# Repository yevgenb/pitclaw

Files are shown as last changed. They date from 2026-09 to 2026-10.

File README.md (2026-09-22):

# Pit Claw logo Pit Claw



BBQ temperature monitor and controller built around the WT32-SC01 Plus: an
ESP32-S3 with a 3.5-inch, 480×320 landscape capacitive touchscreen. Pit Claw reads
one pit probe and two meat probes, controls a blower and optional servo damper,
and provides a web dashboard for monitoring and control. The touchscreen and
temperature control work without Wi-Fi.

## Current project state

As of **9 September 2026**:

| Area | State |
| --- | --- |
| Firmware | Version **0.2.0**, built and flashed to a WT32-SC01 Plus; upload verified and the device responded after reboot. |
| Touchscreen | LVGL Home, Graph, Settings, temperature editors, shared alarms, and first-boot setup are implemented. The latest polish is included in the flashed build. |
| Web interface | Live temperatures, history and prediction graphs, session controls/export, settings, and manual firmware OTA. Supports deployment under an Nginx path prefix. |
| Carrier PCB | **Rev B-T2F0-A5807-S4** routed prototype. Recorded KiCad ERC, DRC, schematic parity, and unconnected-item checks pass. A reviewed bare-board fabrication package is available; physical qualification remains. |
| Enclosure | **r7 landscape fit prototype**, with exported STLs, fit coupons, and a print guide. Physical module and printed-part fit still need verification. |

The firmware and simulator builds, **132 native test cases**, and the headless
LVGL checks passed on 8 September 2026. The LVGL checks include 123 navigation
taps and editor, unit, alarm, probe-state, and layout transitions. This validation
does not establish smoker temperature accuracy or qualify the new carrier's
electrical loads, thermal behavior, or physical fit.

## Touchscreen

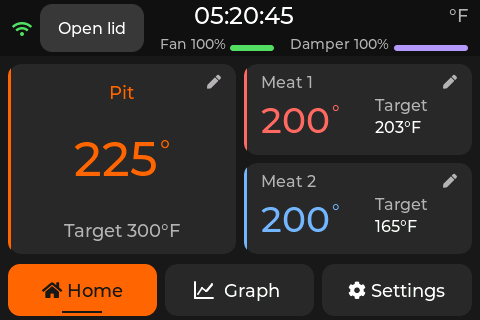
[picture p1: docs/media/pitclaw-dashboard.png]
Current Pit Claw touchscreen dashboard


The current dashboard uses large temperature readings, rounded cards and
navigation buttons, neutral status labels, and consistent edit icons. Smaller
degree symbols follow changing values and disappear for disconnected probes.
The image above is a native 480×320 LVGL render with example readings.

- Tap the pit card to change its setpoint, or a meat card to edit that probe's
  target. Tap for one-degree steps or hold for five-degree steps; Cancel discards
  the draft value.
- Switch between Fahrenheit and Celsius without changing the stored control
  targets. Graph history uses elapsed sample time and a dashed setpoint line.
- Alarm controls remain available on Home, Graph, Settings, and above an open
  editor. Disconnected probes display dashes.
- Setup provides Back navigation, Wi-Fi connection feedback, live probe checks,
  and separate fan, servo, and buzzer test buttons.

## Control and monitoring

- **Three probe inputs:** one pit and two meat channels, using calibrated
  thermistor probes with 2.5 mm jacks. Thermoworks Pro-Series is the intended
  probe family; other probes require suitable coefficients and calibration.
- **PID control:** fan-only, fan-and-damper, and damper-priority modes, with
  startup handling, lid-open detection, and output shutdown on a pit-probe fault.
- **Alarms:** local buzzer, browser audio, and configurable Pushover notifications.
- **Cook sessions:** temperature history, predicted meat completion times, and
  CSV/JSON export. Download a session before starting a new one.
- **Configuration:** persistent settings, probe calibration, and Wi-Fi reconnect.

## Web interface

Pit Claw web dashboard

Open `http://bbq.local` or the controller's LAN IP from a device on the same
network. The dashboard uses WebSocket updates and also works behind an Nginx
directory prefix such as `/newbbq/`; see the
[reverse-proxy guide](firmware/docs/reverse-proxy.md).

PWA installation, service-worker caching, and browser notifications need a secure
context; use HTTPS on the reverse proxy for those features. Live readings still
require a connection to the controller.

Manual firmware updates are available at `/update`. Automatic GitHub release
checks are disabled in the current PlatformIO configuration. `firmware.bin`
includes the web UI, so one firmware upload updates both interfaces while
preserving LittleFS settings and session history.

## Hardware and enclosure

The active design is the
[Rev B-T2F0-A5807-S4 carrier](hardware/carrier-revb/README.md), a 60×92 mm board
with PCB-mounted probe jacks, a blower/servo connector, a 12 V barrel inlet,
an Adafruit 5807 USB-C PD module, and a Traco TSR 2-2450N 5 V / 2 A converter.
A relay selects wall power when present and USB-PD otherwise.

| Resource | Contents |
| --- | --- |
| [Carrier design](hardware/carrier-revb/README.md) | Circuit, power limits, module mounting, and remaining qualification work |
| [Wiring guide](docs/wiring.md) | Current connector pin assignments and assembly wiring |
| [Carrier BOM](hardware/carrier-revb/bom/README.md) | Current parts and recorded pricing |
| [Verification](hardware/carrier-revb/verification/README.md) | Native electrical/layout checks and physical validation limits |
| [JLCPCB prototype package](hardware/carrier-revb/fabrication/jlcpcb-2026-09-06/README.md) | Reviewed Gerber/drill archive for a small bare-board order |
| [Fusion enclosure model](enclosure/fusion-r13/pitclaw-enclosure-r13.f3d) | Editable 104×86×44.9 mm controller case |
| [STL package and print guide](enclosure/fusion-r13/README.md) | Top, bottom, probe fascia, display retainer, USB base, coupons, and assembly guide |

The fabrication documentation records no submitted PCB order. Carrier load,
relay-transfer, thermal, and module-fit checks remain, along with printed
enclosure fit checks. Use the [enclosure guide](enclosure/README.md) for the
current controller case and the separate fan/damper assembly.

## Getting started

### 1. Set up the tools

```sh
git clone https://github.com/yevgenb/pitclaw.git
cd pitclaw
```

Install PlatformIO CLI. Windows users can use the repository's setup script:

```powershell
# Run from an elevated PowerShell in the repository root
powershell -ExecutionPolicy Bypass -File scripts\setup-dev.ps1
```

See [firmware development](docs/firmware-development.md) for prerequisites.
Use the current carrier and wiring guides when assembling hardware.

### 2. Build and flash

Run from `firmware/` with the WT32-SC01 Plus connected over USB:

```sh
cd firmware
pio run -e wt32_sc01_plus
pio run -e wt32_sc01_plus --target upload

```

No filesystem upload is needed for the web UI. A filesystem upload replaces
LittleFS and can erase configuration and session data; normal firmware updates
preserve that filesystem. The display board's programming USB port requires
opening the enclosure; the carrier's external USB-C PD port is for power.

For later manual firmware OTA, open `http://bbq.local/update` and upload
`firmware/.pio/build/wt32_sc01_plus/firmware.bin` from the repository root.

### 3. Complete setup

1. Select °F or °C in the touchscreen wizard.
2. Follow the Wi-Fi QR code and portal instructions, or continue offline with Next.
3. Connect the probes and check their live readings.
4. Tap the fan, servo, and buzzer test buttons and confirm each device operates.
5. Finish setup to enter the dashboard.

Hold a finger on the touchscreen for 10 seconds during the boot splash to request
a factory reset.

## Development and validation

The SDL2 desktop simulator runs the production LVGL screens and serves the web
UI at `http://localhost:3000`. Run these commands from `firmware/`:

```sh
# Native control-logic regression tests
pio test -e native

# Desktop simulator; requires SDL2
pio run -e simulator
.pio/build/simulator/program

# Headless production LVGL interaction checks; run after building the simulator
python3 test/ui/run_checks.py

# Web update and reverse-proxy checks
node test/web/test_release_updates.cjs
node test/web/test_reverse_proxy.cjs
```

On Apple Silicon with Homebrew SDL2, use
`CPATH=/opt/homebrew/include pio run -e simulator` if the headers are not found.
The [display test guide](firmware/test/ui/README.md) explains the capture command
and alternate SDL paths. UI screenshots can be regenerated locally on demand.

| Guide | Topics |
| --- | --- |
| [Firmware development](docs/firmware-development.md) | Build, flash, architecture, and configuration |
| [Display checks](firmware/test/ui/README.md) | Real LVGL pointer events, layout checks, and PNG capture |
| [Web UI development](docs/web-development.md) | Simulator profiles, web assets, and WebSocket protocol |
| [Reverse proxy](firmware/docs/reverse-proxy.md) | Nginx path prefixes, WebSockets, HTTPS, and manual OTA routing |
| [3D printed parts](enclosure/README.md) | Current enclosure, legacy parts, and fan assembly |

## License

TBD

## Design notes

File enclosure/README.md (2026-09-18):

# Pit Claw 3D printed parts

The controller enclosure is [Fusion r13](fusion-r13/README.md): a 104 × 86 ×
44.9 mm case with a top bezel, bottom shell, internal display retainer and
removable probe fascia with fitted captured guides. All sixteen insert pilots
are Ø4.2 mm; the full parts include the accepted guide and seam adjustments.
Four internal M3 inserts provide a 72 × 74 mm mounting pattern with screw access
from underneath.

A fifth printable part, the [Adafruit 5807 base](fusion-r13/usb-base/README.md),
replaces both module spacers and the adhesive rear support. It uses the existing
M2 hardware and keeps the same 3 mm board seating height. The user confirmed
the original R13 case fit; its four enclosure parts are unchanged, so **no case
reprint is needed**. Only the new base needs a physical fit check.

- [Print package and editable Fusion model](fusion-r13/pitclaw-enclosure-r13.zip)
- [Print settings, coupons, hardware and assembly](fusion-r13/README.md)
- [Native Fusion design](fusion-r13/pitclaw-enclosure-r13.f3d)
- [Mounting interface](fusion-r13/mount-interface.json)
- [Independent OpenSCAD reference and checks](fusion-r13/reference/README.md)
- [Matching joint coupons](fusion-r13/README.md#coupons) for checking the same guide,
  seam and insert geometry used by the complete enclosure.

The current package has five complete parts and six coupons. Only the latest
controller enclosure is kept in the working tree; older designs remain in Git
history. CAD checks pass. Printed strength and mounting load capacity remain
unrated.

## Separate blower and damper assembly

The smoker-mounted blower/damper is a separate part, retained alongside the
controller enclosure. Use [bbq-fan-assembly.scad](bbq-fan-assembly.scad),
[blower-housing.stl](stl/blower-housing.stl) and
[uds-pipe-adapter.stl](stl/uds-pipe-adapter.stl).

Open the fan source in OpenSCAD, select the desired `part`, render and export in
millimeters. Print the blower housing open-side-up and the pipe adapter upright.
Check fit with the actual fan, servo and smoker intake. Its geometry is separate
from the r13 controller fit verification.

### Hardware

| Qty | Item | Notes |
|-----|---|---|
| 2 | M3x10mm screws | Mount 5015 blower fan to housing |
| 2 | M2 or M2.5 screws | Mount MG90S servo (servo-specific) |
| 1 | Small screw + nut | Attach damper plate to servo horn |
| 2 | Small hose clamps (25-40mm range) | One for pipe adapter to pipe nipple, one for duct to adapter (if not press-fit) |
| 1 | High-temp gasket tape (or PTFE tape) | Wrap around NPT pipe before inserting into adapter for air-tight seal |

### Assembly

1. **Mount the servo**: Press-fit or screw the MG90S servo into the servo pocket on the intake side of the blower housing.

2. **Attach damper plate**: Attach the butterfly damper plate to a servo horn using a small screw. The damper plate should be centered in the intake opening when the servo is at its midpoint.

3. **Install the servo horn**: Press the horn with damper plate onto the servo shaft. Verify the damper opens fully (parallel to airflow) and closes fully (perpendicular to airflow) across the servo's range of motion.

4. **Mount the blower fan**: Place the 5015 blower into the housing cavity. Secure with 2x M3x10mm screws through the top mounting holes.

5. **Prepare the UDS pipe adapter**: Wrap high-temp gasket tape around the 3/4" NPT pipe nipple on the drum. Slide the pipe adapter over the nipple and secure with a hose clamp in the groove.

6. **Connect housing to adapter**: Insert the blower housing output duct into the adapter's duct mating end. If the fit is loose, secure with a second hose clamp. If press-fit is snug, no clamp is needed.

7. **Route wires**: Run the fan power wires (2-pin) and servo signal wires (3-pin) through the wire channels on the housing, back to the controller enclosure.

### Airflow Path

```
Outside air -> [butterfly damper] -> [5015 blower fan] -> [duct] -> [UDS pipe adapter] -> drum
               (servo controlled)    (PWM speed)          (sealed)   (clamped to pipe)
```

The PID controller modulates both the fan speed (PWM) and damper position (servo angle) to maintain the target pit temperature. Cap all other intake pipes on the UDS -- this assembly controls all airflow.

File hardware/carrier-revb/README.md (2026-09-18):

# Rev B-T2F0-A5807-S4 carrier PCB — routed prototype

The KiCad project contains the reviewed relay circuit and two-layer copper routing.
See [current native verification](verification/README.md), the
[schematic preview](previews/schematic/pitclaw-carrier.svg), and
[PCB previews](previews/routed/). The
[JLCPCB package](fabrication/jlcpcb-2026-09-06/README.md) targets a small bare-board
prototype order and includes exact-archive Gerber/drill checks. Physical module
and enclosure fit, load and thermal qualification remain. No order is submitted.

This revision replaces the socketed Mini100 with a soldered, through-hole
**Traco Power TSR 2-2450N** fixed 5 V / 2 A converter and removes **F1, F2, F3
and F4**. J9 provides a 5.5 × 2.1 mm center-positive wall-adapter inlet.
K1 automatically selects wall power when its 12 V coil is energized, and USB-C
PD otherwise. JP2 is removed, so changing supplies does not require opening the
case. J9 switches its sleeve, so its pin 3/C is deliberately unused. The 12 V
input, WT32 5 V feed, MG90S 5 V feed and switched blower output have no series
fuses. Use only protected/current-limited regulated 12 V sources rated no more
than 3 A; the carrier has no onboard or branch-selective overcurrent protection.

The S1 simplification also removes D1, C5, C7, C13, R17 and R18. Q3, R7 and R19
remain removed. GPIO14 drives the passive piezo through R6 (330 ohm). The owned
ADS1115 module must provide its own local supply bypassing and SDA/SCL pull-ups.

## Board architecture

- Candidate carrier: 60 × 92 mm, two layers, through-hole parts except the
  preassembled Adafruit 5807 and ADS1115 modules.
- Four 3.2 mm carrier clearance holes form an independent 51 × 58 mm M3
  pattern: (4.5, 4.5), (55.5, 4.5), (4.5, 62.5), (55.5, 62.5) mm.
  M3 screws attach the carrier to heat-set inserts in the bottom shell. Reserve
  7 mm diameter for top screw/washer hardware and 9 mm for underside insert
  bosses. The WT32 mounts separately in the top assembly.
- All external connectors occupy the two short ends for landscape use. J2,
  J9 face Y = 93.5 mm; MOD1 USB-C is set back to Y = 91.5 mm for the exterior
  recess. J4–J6 face the opposite end
  at Y = -3 mm. Two isolated underside supports at X = 2–5 and 56–59 mm,
  Y = 90.7–92 mm support the power end; matching B.Cu keepouts exclude copper,
  soldered pads and vias from their contact patches. The M3 underside reservations
  also cover the 4 mm installation slide; the whole carrier sits 4.5 mm toward
  the power end in the enclosure.
- MOD1: Adafruit 5807 HUSB238 USB-C PD breakout, 20.32 × 23.495 mm. Its two
  documented 2.5 mm holes mount over 2.4 mm H5/H6 carrier holes.
- U2: TSR 2-2450N, 14 × 7.6 × 10.2 mm SIP-3, pin 1 VIN, pin 2 GND, pin 3 VOUT.
  The pin row is offset within the body. The order review corrected that offset,
  adopted Ø1.4 mm holes / Ø2.0 mm pads for its tolerated square pins and moved
  the converter 0.75 mm toward the probe end.
- J8: socket for the owned blue 10-pin ADS1115 board. Its header pitch and body
  offsets still require a physical fit check. Confirm local bypassing and measure
  continuity from SDA/SCL to VDD through the module pull-ups before assembly.
- J2: unmagnetized 8P8C connector for the HeaterMeter blower/servo cable. It is
  **not Ethernet** and must never be connected to network equipment.
- J4–J6: three PCB-mounted Same Sky MJ1-2503A 2.5 mm probe jacks.
- J9: Tensility 54-00133, 5.5 × 2.1 mm center-positive switched DC jack,
  right-angle THT. Pin 1/A feeds WALL_12V, pin 2/B is GND and pin 3/C is unused.
- K1: G5Q-1 DC12 SPDT relay. NC = PD_12V, NO = WALL_12V, COM = +12V.
  The raw wall input powers its coil; D3 (SB140) is the coil flyback diode.
  NC is rated 3 A / 30 VDC and NO 5 A / 30 VDC. The 12 V coil uses 0.4 W.
- J1/J7/J3: carrier-side JST-XH harness headers to the 5807 and WT32. J1 and J7
  use the same housing but carry different voltages; label and route them
  separately.

## Power and connector mapping

```text
Adafruit 5807 V+ -> J1 -> PD_12V ----> K1 NC
12 V wall adapter center -> J9 pin 1 -> WALL_12V -> K1 NO + coil
K1 COM -> +12V -> U2 VIN and Q1 source
K1 coil return -> GND; D3 cathode WALL_12V, anode GND
wall adapter sleeve -> J9 pin 2 -> GND; J9 pin 3 is unused
U2 pin 3 -> +5V ----> JP1 -> WT32 EXT pin 1
                     +-----------------------> RJ45 pin 3 (MG90S +5 V)
WT32 DEBUG 3.3 V ---> J7 -> ADS1115/probe excitation only

Q1 drain -> FAN_OUT --------------------------> RJ45 pin 5
common GND -----------------------------------> RJ45 pin 4
GPIO13 -> R4 ---------------------------------> RJ45 pin 6 (servo signal)
```

RJ45 pins 1, 2, 7 and 8 are unused. Its contacts are rated 1.5 A each; pin 4
carries the combined blower and servo return. Keep the combined load within
that contact rating and verify startup and contact heating.
[Amphenol contact specification](https://cdn.amphenol-cs.com/media/wysiwyg/files/documentation/s6032c_rjhse.pdf). JP1 is power-source isolation, not a fuse;
remove its shunt before powering/programming the WT32 through its own USB port.

K1 selects one input at a time. Both sources may be connected; powered wall input
has priority, while an unpowered barrel plug leaves USB-PD selected. No jumper
change is required. The break-before-make transfer may restart the controller;
D3 slows coil release. This circuit does not supervise wall-voltage quality.
Verify inrush, supply brownout and loaded switching before use.

The jack’s NC contact joins pins 2/B and 3/C, not 1/A and 3/C. S2 would short
PD to ground with J9 empty. S3 used an internal manual selector; S4 removes that
usability problem with K1. After the [price and complexity comparison](power-input-review.md),
the final decision on 2026-09-06 retains the relay: USB-PD on NC and wall on NO,
with low contact loss and straightforward through-hole assembly.
See the [G5Q contact and coil ratings](https://omronfs.omron.com/en_US/ecb/products/pdf/en-g5q.pdf).

The ADC is intentionally powered from the WT32 DEBUG 3.3 V rail, so there is no
carrier 3.3 V LDO. Keep motor currents off that harness and verify the loaded
rail before relying on it.

## Retained functional circuitry

The fuses and carrier TVS are gone, but the following functional parts remain:

- The Adafruit 5807/HUSB238 power path handles USB-PD negotiation and output
  overvoltage shutdown. The former P6KE18A began breaking down above 17.1 V,
  later than the HUSB238's 1.2× requested-voltage OVP for a 12 V request, so D1
  did not add useful first-response protection in this prototype.
- D2 is the SB140 blower flyback clamp and is required for the inductive load.
- Start two-wire blower power PWM at 100 Hz with a 100% kick-start; confirm the
  actual blower starts reliably and Q1 stays cool before tuning frequency/duty.
- Q1/Q2 form the 12 V high-side blower switch and level translation from the
  WT32's 3.3 V GPIO.
- C1/C2 and C3/C4 are input/output decoupling. One 470 uF C3 replaces the former
  220 uF C3 plus 100 uF C5 while remaining below U2's stated 820 uF maximum,
  before downstream capacitance is counted.
- Q1 is now the lower-cost IRF5305PBF with the same TO-220 gate/drain/source pin
  order; BZ1 is the lower-cost TDK PS1240P02BT passive piezo.
- R5 and R10-R12 use one common 10 k, 1% part. At B≈3950, a 1% bias-resistor
  error is roughly 0.23 °C at 25 °C, 0.35 °C at 100 °C and 0.45 °C at 150 °C;
  calibrate each probe channel.

The TSR 2-2450N has internal current limiting, continuous short-circuit
protection and automatic recovery, but its specified typical 5 V-model current
limit is 360% of its 2 A rated output. Treat that as converter self-protection,
not precise protection for the MG90S, blower, cable, connector or PCB traces.

## Reduced enclosure stack

Mechanical revision r3 reduces the enclosure to 44.9 mm by lowering the carrier
onto 5 mm posts and mounting Q1 flat. Q1 uses the custom
`IRF5305_TO220_Horizontal_TabDown` footprint with 1.4 mm lead drills and an F.Cu
keepout beneath its live drain tab and formed leads. Maintain a 1 mm cured
insulating support and secure the body with side adhesive fillets for transport;
there is no tab bolt. Form the leads before soldering while supporting them
near the package. The 6.5 mm fitted-height allowance still requires a sample
and thermal check. Exact electrical parts and nets are unchanged.

The 16 mm overall carrier component allowance also covers the 14 mm C1,
socketed ADC and mated JST-XH wiring. Verify complete assemblies, including wire
turns, fit that allowance. K1 alone reserves 16.2 mm including its molded feet;
the enclosure checks its local clearance separately without increasing case depth. See the [revised case stack](../../enclosure/fusion-r13/README.md).

Q1 dimensions use [Infineon's current datasheet](https://www.infineon.com/dgdl/Infineon-IRF5305-DataSheet-v01_01-EN.pdf?fileId=5546d462533600a4015355e370101993)
(Rev 2.1, 2026-07-24): maximum 10.67 × 16.51 × 4.83 mm body.
The 6 mm body-to-pad-row offset allows the bend beyond the widened lead area.
Follow [Infineon's assembly guidance](https://www.infineon.com/assets/row/public/packages/73/package_download/infineon-board-assembly-recommendations-to-package-en.pdf)
and verify the formed sample before soldering.

## Adafruit 5807 mount and stack

The active mount is documented in [mechanical/adafruit5807](mechanical/adafruit5807/README.md).
The module occupies X = 34.34–54.66 mm and Y = 66.862–90.357 mm, with H5/H6 at
(36.753, 87.817) and (51.993, 87.817) mm. Its PCB front edge is 1.643 mm inside the carrier
power edge. The USB-C face remains 1.143 mm beyond the module PCB, placing it
at carrier Y = 91.5 mm: **0.5 mm inside the carrier edge**.

Use the [printed USB base](../../enclosure/fusion-r13/usb-base/README.md) with
the existing two M2 screws, four washers no larger than Ø5 mm and two nuts
under the carrier. It replaces both 3 mm nylon spacers and the adhesive rear
support. Its **total seat height remains 3 mm**, preserving connector and WT32
clearances; do not add spacers beneath it. The
[current enclosure fit prototype](../../enclosure/fusion-r13/README.md) provides
flush RJ45/barrel openings and a 2 mm-deep outside USB pocket. The USB face
is level with the pocket floor, inside a fitted 10.14 × 4.7 mm opening.
The cable housing sits in the 20 × 10 mm exterior pocket. Internal backing
has blind PCB/head clearances, with at least 0.943 mm of plastic locally;
there are no exterior board/hardware cutouts. The main carrier-edge channel
remains. Solid plastic separates the three ports. The original R13 case fit
has been confirmed and its four printed case parts are unchanged. Fit-check
the new base, full cable insertion and the populated carrier's slide-in path.

The board-mount holes and module body have an F.Cu/B.Cu keepout with no current
component-courtyard collisions. Connect V+/GND to J1 with a short secured
20–22 AWG pair through the base's rear wire gap. No terminal block belongs
under the module. Limit module solder tails to 2.5 mm below its underside,
leaving 0.5 mm above the carrier. Rear stops resist insertion; the two M2
clamps carry extraction. The wires must not carry USB insertion force.

## Design files

- `pitclaw-carrier.kicad_pro`, `.kicad_sch`, `.kicad_pcb`: editable KiCad 9
  project.
- `tools/build_draft.py`: schematic generator; defaults to preserving routed PCB copper.
- `tools/export_enclosure_interface.py`: exports actual carrier mount and socket
  coordinates to `mechanical/enclosure-interface.json` and the enclosure's
  generated `carrier-interface.scad`.
- [Current enclosure fit prototype](../../enclosure/fusion-r13/README.md): bottom
  carrier mounts, top display mounting, connector openings and fit-test gates.
- `verification/`: native ERC/DRC plus independent pin/net, BOM and mechanical
  checks.
- `previews/pitclaw-carrier-schematic.pdf` and `.png`: full schematic, with enlarged section PNGs alongside.
- `previews/schematic/`: native schematic SVG.
- `previews/routed/`: native copper-layer and assembly previews.
- `bom/selection.json`: exact part selection and captured DigiKey pricing.
- `bom/pitclaw-carrier-digikey-bom.xlsx`: editable priced BOM.

The routed PCB is authoritative for copper. Keep it alongside the project rules,
custom footprints and schematic. Power trunks use wider copper than signal
traces; see [routing notes](routing.md) for widths, returns and reproduction.

## Reproduce the checks

Use KiCad 9's Python interpreter with `pcbnew` available. From this directory:

```sh
python3 tools/build_draft.py --schematic-only
python3 tools/export_enclosure_interface.py
python3 tools/check_draft.py
```

The schematic-only mode preserves PCB copper and project rules. Explicit
`--rebuild-unrouted-pcb` refuses an existing routed board. The checker exports
fresh ERC, DRC and schematic parity reports and requires zero unconnected items.
It also checks the physical pin maps, source-selection states, BOM and mechanical
reservations. `PITCLAW_KICAD_CLI` and `PITCLAW_KICAD_SHARE` override the default
macOS KiCad paths. Regenerating geometry requires refreshing enclosure verification.

## Prototype assembly and qualification

The fabrication package records the native and exported-file order checks.
The following physical checks remain for assembly and use. In particular, the
exact owned ADC module's header offsets and seated height remain a possible
first-board respin risk; measuring them before ordering reduces that risk.

1. Configure the Adafruit 5807 for 12 V / 3 A and confirm voltage/polarity with a meter before connecting J1.
2. Fit-check J9 against the Tensility drawing and sample. With all power removed,
   confirm continuity from pins 2–3 only when no barrel plug is inserted. Confirm
   pin 3 is otherwise unconnected. Verify K1 selects PD when de-energized and wall
   power when energized, including an unpowered barrel plug and both sources. Use a
   regulated center-positive 12 V adapter rated no more than 3 A.
3. Confirm the owned ADS1115 has local bypassing and SDA/SCL pull-ups to VDD.
4. Fit-check U2, J2, J4–J6, the ADS1115 socket/support, 5807 mounting stack and USB cable overmold.
5. Measure the WT32 plus MG90S 5 V startup/current transients and the actual
   blower current. Verify the shared RJ45 ground contact under combined load.
6. Confirm antenna, enclosure, screw, rear-component, barrel-plug and USB clearances
   using the [current enclosure fit prototype](../../enclosure/fusion-r13/README.md).
   The user confirmed the original R13 case fits; the new printed USB base still
   needs its physical fit check. Earlier perfboard enclosure SCAD/STLs remain
   legacy designs and do not fit this carrier.
7. Validate the routed power paths against measured current, voltage drop and
   enclosed temperature. Confirm the combined fan/servo return stays within
   J2's 1.5 A/contact rating and D2 is suitable for the measured freewheel load.
8. After any CAD edit, rerun ERC, DRC, parity and drawing checks, then inspect
   regenerated Gerbers and plated/nonplated drills. Use the verified release ZIP
   rather than an intermediate routing or export file.
9. Bring up from a current-limited bench supply with loads disconnected, then
   test the blower and servo separately and together.

## Key sources

- [TSR 2-2450N product page](https://www.digikey.com/en/products/detail/traco-power/TSR-2-2450N/25903121)
- [Tensility 54-00133 product page](https://www.tensility.com/products/54-00133)
- [Tensility 54-00133 drawing](https://tensility.s3.us-west-2.amazonaws.com/imports/product_spec_sheets/54-00133.pdf)
- [Adafruit 5807 product page](https://www.adafruit.com/product/5807)
- [Adafruit HUSB238 guide](https://learn.adafruit.com/adafruit-husb238-usb-type-c-power-delivery-breakout)
- [Hynetek HUSB238 product page](https://en.hynetek.com/2421.html)
- [Infineon IRF5305 product page](https://www.infineon.com/part/IRF5305)
- [TDK PS1240P02BT product page](https://product.tdk.com/en/search/sw_piezo/sw_piezo/piezo-buzzer/info?part_no=PS1240P02BT)
- [Traco TSR 2N series datasheet](https://www.tracopower.com/tsr2n-datasheet)
- [User-identified ADS1115 module](https://components101.com/modules/ads1115-module-with-programmable-gain-amplifier)
- [WT32-SC01 Plus V1.3 manual](https://github.com/janick/WT32-SqLn/blob/main/docs/WT32-SC01-Plus-V1.3-EN.pdf)
- [Same Sky MJ1-2503A drawing](https://www.sameskydevices.com/product/resource/mj1-2503a.pdf)
- [Amphenol RJHSE-x080 drawing](https://cdn.amphenol-cs.com/media/wysiwyg/files/drawing/rjhsex080.pdf)
- [HeaterMeter blower/servo wiring](https://github.com/CapnBry/HeaterMeter/wiki/Blower-and-Servo-Wiring)

No parts have been ordered and no manufacturing files have been submitted.

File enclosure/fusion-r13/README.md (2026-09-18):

# Complete enclosure — Fusion r13

R13 includes the **complete enclosure**—bottom, top, removable probe fascia and
internal display retainer—plus a printed Adafruit 5807 base. The overall case
remains **104 × 86 × 44.9 mm**. PCB, screen, connector positions and the
72 × 74 mm accessory-mount pattern are unchanged.

The user has confirmed the existing R13 case fit. **Its four enclosure parts
have unchanged geometry and do not need reprinting.** Print only the new USB
base if the case is already made. The base's physical fit still needs checking.

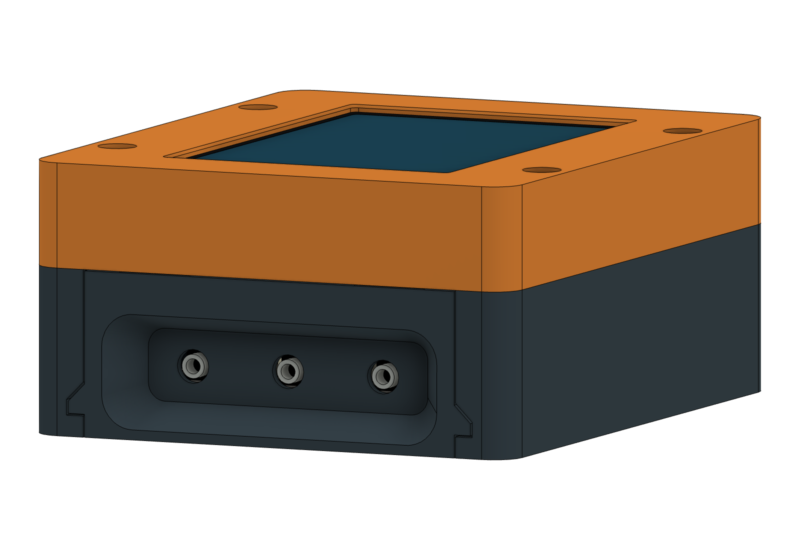
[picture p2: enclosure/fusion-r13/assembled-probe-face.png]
Complete R13 enclosure


## Files

- [Complete Fusion model](pitclaw-enclosure-r13.f3d)
- [Enclosure and print package](pitclaw-enclosure-r13.zip)
- `step/`: five complete part exports.
- `stl/`: five complete parts and six coupons: **11 STLs**, oriented for printing.
- [Adafruit 5807 base and installation](usb-base/README.md)
- [Guide review](guide-review.md) · [Mount review](mount-review.md)
- [Mount dimensions](mount-interface.json) · [Mount-hole drawing](mount-pattern.dxf)

The five complete print meshes come from Fusion. Coupon meshes come from the
independent reference. Electronics shown in Fusion are reference geometry.

| STL | Size, mm | Orientation |
|---|---|---|
| [carrier-bottom.stl](stl/carrier-bottom.stl) | 86 × 104 × 27.6 | Floor down |
| [carrier-top.stl](stl/carrier-top.stl) | 86 × 104 × 21.9 | Display face down |
| [carrier-retainer.stl](stl/carrier-retainer.stl) | 80 × 96 × 2.5 | Flat |
| [probe-fascia.stl](stl/probe-fascia.stl) | 72 × 27.4 × 9.8 | Outside probe face down |
| [adafruit5807-base.stl](stl/adafruit5807-base.stl) | 23.32 × 24.995 × 4.2 | Flat floor down; no supports |
| joint-coupon-bottom.stl | 33 × 30 × 27.6 | Floor down |
| joint-coupon-top.stl | 33 × 30 × 21.9 | Display face down |
| joint-coupon-fascia.stl | 26 × 27.4 × 9.8 | Outside probe face down |
| fit-coupon.stl | 86 × 22 × 27.6 | Floor down; power-end section |
| insert-coupon.stl | 36 × 16 × 7.5 | Flat; 4.0/4.1/4.2 mm pilot trials |
| mount-coupon.stl | 16 × 21 × 10 | Floor down; local accessory-mount section |

## Fits and hardware

The guide has **0.30 mm outer-side clearance**, **0.40 mm normal roof
clearance** and **0.30 mm lower running clearance**. Two small bearing lands
remain at Z3.8 to keep the fascia level and the probe holes at Z11.65. The
early ramp establishes that height before the jack collars enter. The inward
stop stays at Y−43; the pocket floor stays at Y−44.5.

Fascia side, upper-edge and rear-floor joints have **0.20 mm nominal gaps**.
The rear-floor gap is along Y, not a change in seating height. The bezel/bottom
seam closes at Z27.6. The locating lip has 0.30 mm nominal straight/corner
clearance, using outer radius 2.2 and unchanged inner radius 1.0.

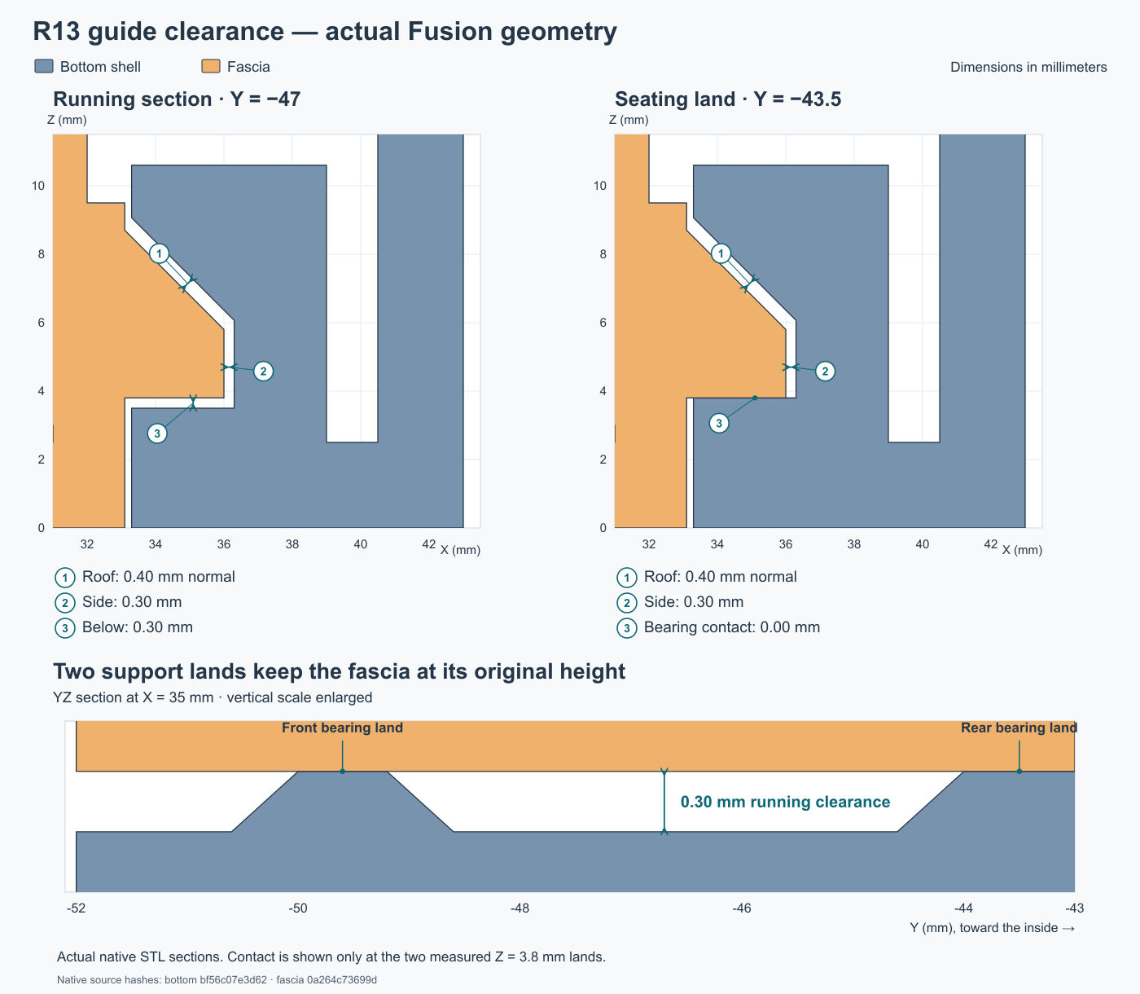
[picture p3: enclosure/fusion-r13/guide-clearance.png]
Current guide clearances and seating lands


The probe pocket retains its 60 × 19 mm entry, 50 × 12 mm floor and 7.5 mm
depth. The downward cable clearance remains as accepted. Use the complete
fascia to check all three actual probe plugs together.

All **16 heat-set pilots are Ø4.2 mm, 5 mm deep**, for the user's M3 inserts
measured at **4.0–5.0 mm outside diameter**. A 4 mm insert length is still an
assumption to confirm. Screw passages remain Ø3.4 mm. The insert coupon's
rightmost bore is the selected 4.2 mm size; heat-set retention requires a
physical check in the chosen material.

| Quantity | Hardware |
|---:|---|
| 16 | User's short M3 inserts: four carrier, four closure, four retainer, four accessory mounts |
| 4 | M3 × 6 carrier screws with 0.5 mm insulating washers, OD ≤7 mm |
| 4 | M3 × 18 closure screws; head OD ≤6 mm, height ≤3 mm |
| 4 | M3 × 6 button-head screws for retainer anchors |
| 4 | Small screws matched to the actual WT32 rear blind bosses |
| 1 | Soft perimeter strip on the inactive display border; establish preload physically |
| 1 | Printed Adafruit 5807 base; total board seating height 3 mm |
| 2 sets | Existing USB-module M2 screws, washers and nuts |

The fascia and USB base add no screws or inserts. The base replaces both 3 mm
nylon spacers and the adhesive rear support; do not stack them under it. USB
hardware must remain within Ø5 mm, with at most 2 mm above its PCB and 3.3 mm
below the carrier. Trim module solder tails to at most **2.5 mm below the module**,
leaving 0.5 mm above the carrier. Other carrier tails remain limited to 3 mm.
Accessory-mount screws enter from outside; choose their length for **6.5–7 mm
protrusion from the bracket's case-contact surface**, accounting for washers.

## Assembly and test

1. Check the inserts in a coupon, then install them with the bottom empty and
   top removed. The mount coupon does not reproduce the full-height tool path.
   Fit the USB module on its [printed base](usb-base/README.md), using the
   existing two M2 fasteners. Route its output wires through the rear gap.
2. Leave fascia and top off. Lower the carrier 4 mm toward the probe end from
   its final position, 0.3 mm above the posts. Slide it 4 mm toward power, lower
   onto the posts, then fasten it.
3. Slide the fascia inward over the three jack noses to its rear stops. Its
   ramps and lands establish the original height. Do not lever it on the jacks.
4. Attach the retainer to the WT32's rear bosses. Fit the display, soft border
   strip and retainer inside the top; connect the harness clear of all joints.
5. Hold the fascia seated and lower the top. The chamfered keys must enter
   freely. Once the seam seats, gently tighten the four closure screws.

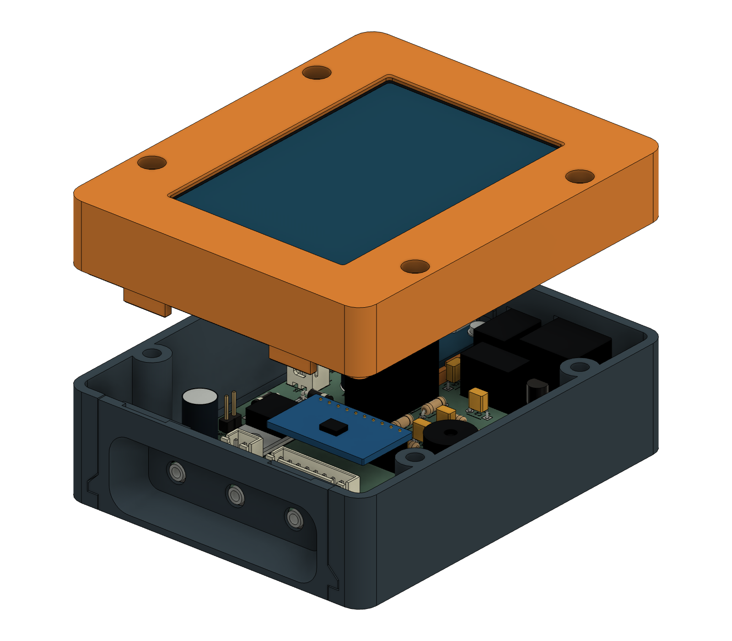
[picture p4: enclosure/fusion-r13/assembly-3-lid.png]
Closing the assembled upper half


For service, remove the top, withdraw the fascia straight off the rails and
jack noses, then unfasten and reverse-slide the carrier.

## Coupons

The three-piece joint coupon includes the real closure post at (38,−28).
Use one insert and an M3 × 18 screw in that **tall post**, not the nearby short
accessory boss. Check closure without the fascia, then with it; do not use the
screw to pull a visibly obstructed joint together. The coupon checks local fit,
not full-case stiffness.

The power-end coupon checks the actual plugs and USB hardware locally. The
mount coupon checks the insert/screw stack but omits full-height tool obstacles.
The insert calibration block retains its labelled 4.0/4.1/4.2 mm trials.

## Printing

Use **100% scale, millimeters**, in the supplied orientations. The starting
settings are a **0.4 mm nozzle, 0.20 mm layers, four perimeters and five solid
top/bottom layers**. Retain the material and settings that worked for the
accepted coupon, and inspect the actual toolpaths rather than assuming every
thin feature accommodates that perimeter count.

The fascia has a 12 mm pocket-floor bridge and 12.6 mm keeper bridges. Inspect
bridge direction, sag and support removal access; supports for the keeper may
need to start on the part. Remove support from all mating surfaces. PETG needs
particular attention to bridges and support release; follow the filament/printer
profile and [Prusa's PETG guidance](https://help.prusa3d.com/article/petg_2059).
For HT-PLA, follow the actual manufacturer's process. If heat treatment is used,
check the coupons after treatment before applying that process to the case;
[Protopasta explains the heat-treatment requirement for its HTPLA](https://proto-pasta.com/pages/high-temp-pla).
These settings do not establish a heat or load rating.

Print the USB base flat, without supports, in the same case material and at
100% scale. Its 0.8 mm floor is already included in the 3 mm seating height.

## Verification and reproduction

The independent reference passes **37 geometry checks and 11 mesh checks**.
Native checks pass **130 component/case pairs**, ten guide-capture checks,
eight seating-land checks, screw/tool access and secondary insert capture.
Measurements from the full native meshes verify **84 hole sections** and
**14 guide sections**. The four enclosure meshes retain their checked geometry.
The USB base also passes eight seat/stop checks, six module-descent checks,
14 solder/peg-envelope checks and two M2-shaft checks; see its
[native report](usb-base/native-verification.json). Its native STL measurements
and reference comparison pass as well. All five native/reference mesh
comparisons pass; the base's maximum sampled difference is below 0.003 mm.
These geometry checks do
not establish the new base's actual solder fit, clamp force or durability.

To reproduce exports, open the R13 archive in Fusion and run `export_r13.py`
through Fusion's Python API. Then, from this directory, use a Python environment
with NumPy, Trimesh, SciPy and rtree, plus OpenSCAD, to run:

```sh
python reference/export_reference.py --copy-coupons
python verify_exports.py
python usb-base/verify_mesh.py
python verify_running_clearance.py
python verify_insert_holes.py
python package_release.py
```

The package is generated only after the checks pass. Geometry changes require
fresh exports, measurements and verification records.

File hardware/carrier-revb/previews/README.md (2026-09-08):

# Current carrier previews

- `pitclaw-carrier-schematic.pdf`: printable vector schematic.
- `pitclaw-carrier-schematic.png`: full schematic overview.
- `schematic-power-inputs.png`, `schematic-regulator.png`,
  `schematic-actuators.png`, `schematic-probes-adc.png`: enlarged sections.
- `schematic/pitclaw-carrier.svg`: native KiCad schematic drawing.
- `routed/carrier-front-copper.svg` and `carrier-back-copper.svg`: actual filled
  copper layers, with PNG versions alongside. The back is mirrored as viewed
  from the solder side.
- `routed/carrier-assembly.svg`: component placement and references.
- `routed/traces/`: routing views with ground fills hidden for readability.
  The ground planes are present in the PCB and in the filled-copper plots.

The editable `.kicad_sch`, `.kicad_pcb` and `.kicad_pro` one directory above
are authoritative. Native verification and its limits are in `../verification`.
`pitclaw-carrier.svg` is a compatibility copy of the current schematic.

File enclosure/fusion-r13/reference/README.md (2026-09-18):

# R13 independent enclosure reference

This self-contained reference contains the accepted enclosure geometry, generated
carrier interface, five full-part STLs and six coupons. It requires no older
enclosure archive or fit-test source. The main release uses native Fusion meshes
for the five complete parts; its six coupons come from this reference.

Run with Python containing `numpy` and `trimesh`, and OpenSCAD installed:

```sh
python enclosure/fusion-r13/reference/export_reference.py --copy-coupons
```

The exporter renders all eleven meshes, runs all 37 assembly/interface checks, and
measures both full guide profiles. `--copy-coupons` copies only the six verified
coupons to `../stl`; it does not replace the five native Fusion part exports.
On macOS it uses the installed OpenSCAD app through `arch -x86_64`; elsewhere it
finds `openscad` on PATH. `--jobs` controls parallel rendering, defaulting to three.

- `carrier-case.scad`, `carrier-interface.scad` and `adafruit5807-base.scad`: complete local geometry inputs.
- `base-geometry.json`: printed USB base dimensions and source geometry.
  The base is included in the carrier insertion and closure sweeps.
- `verify_reference.py`: full assembly sweeps, seated clearances, closure, tool and
  screw access, guide capture and two-land support checks, plus mesh integrity.
- `verify_running_clearance.py`: measurements from actual full-part STL sections.
- `geometry-contract.json`: accepted dimensions and hardware assumptions.
- `fit-verification.json`: combined check, mesh and measured-clearance results.
- `reference-manifest.json`: source, verifier, report and STL hashes.

The working enclosure pilots are Ø4.2 mm for the user's measured Ø5 mm maximum
insert envelope. The calibration coupon deliberately retains its labelled
4.0/4.1/4.2 mm trial holes. Insert length remains the stated 4 mm assumption.

Acceptance of the printed fit coupons does not establish full-case load, heat,
or weather ratings. See the [main assembly guide](../README.md) for the current
parts, hardware, assembly sequence and validation limits.

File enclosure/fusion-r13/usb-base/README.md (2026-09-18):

# Adafruit 5807 printed base

This base replaces **both 3 mm nylon spacers and the adhesive rear support**.
It reuses the existing two M2 screws, four washers and two nuts. The four
enclosure parts are unchanged: **no case reprint is needed**.

- [Print STL](../stl/adafruit5807-base.stl)
- [STEP](../step/adafruit5807-base.step)
- Included in the [current R13 Fusion assembly](../pitclaw-enclosure-r13.f3d)

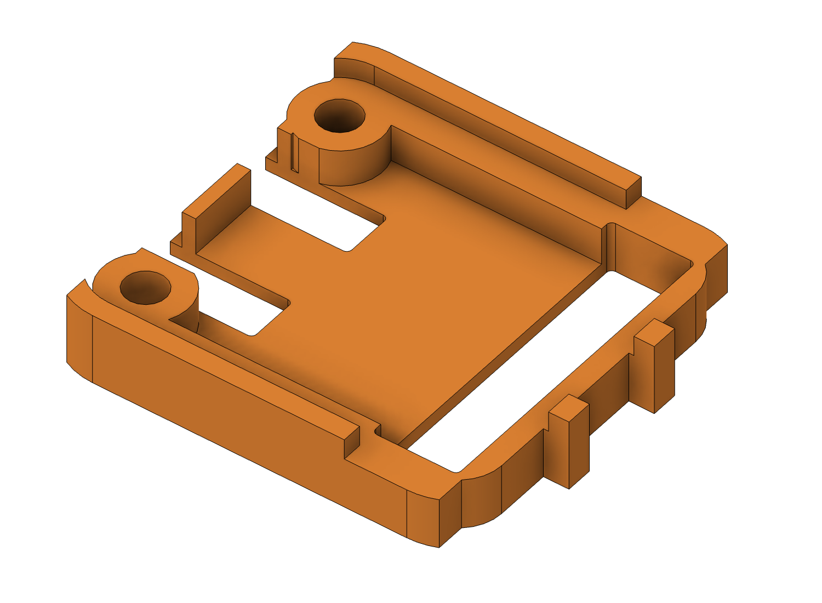
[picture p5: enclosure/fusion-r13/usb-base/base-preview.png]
Printed-base CAD view


## Fit and hardware

| Feature | Dimension |
|---|---:|
| Base footprint / overall height | 23.32 × 24.995 × 4.2 mm |
| Module underside above carrier | **3 mm total** |
| Floor thickness, included in that height | 0.8 mm |
| Sidewall thickness / board-edge clearance | 1.2 / 0.3 mm |
| M2 holes / pitch | Ø2.4 / 15.24 mm |
| Rear wire gap | 5.1 mm, Eagle u=7.8…12.9 |

The hole positions retain the official board's slight asymmetry; align the USB
end with the end containing the two M2 holes. Do not add the former spacers
under the base. The stack remains:

```text
M2 head → washer → module → printed base → carrier → washer → M2 nut
```

Use the existing hardware within the Ø5 mm envelope. Head plus washer must
remain within 2 mm above the module; the nut/washer/tip stack must remain within
3.3 mm below the carrier. Existing M2×10 screws remain a provisional length;
check their actual engagement and protrusion.

## Install

1. Print flat floor down at 100% scale in millimeters, using the same PETG or
   HT-PLA process as the case. Use the 0.4 mm nozzle profile; no supports are
   needed for this base.
2. Inspect the relief windows and holes. Do not fit a terminal block under the
   module. Trim solder tails to **≤2.5 mm from its underside**, leaving 0.5 mm
   clearance above the carrier.
3. Place the base on the carrier, lower the module onto its bearing surfaces,
   and align both M2 holes. Route the output wires over the module's top through
   the gap between the two rear stops; do not trap them under a bearing edge.
4. Fit the existing washers, screws and nuts. Seat the board without bowing it,
   check the socket position, and tighten both clamps. Check the actual cable
   before installing the carrier in the case.

The reinforced rear stops resist insertion. **The M2 clamps carry extraction**;
the side/front corner guides do not provide a strong front stop within the
case pocket's small clearance. Do not rely on the wires or case wall to retain
the module.

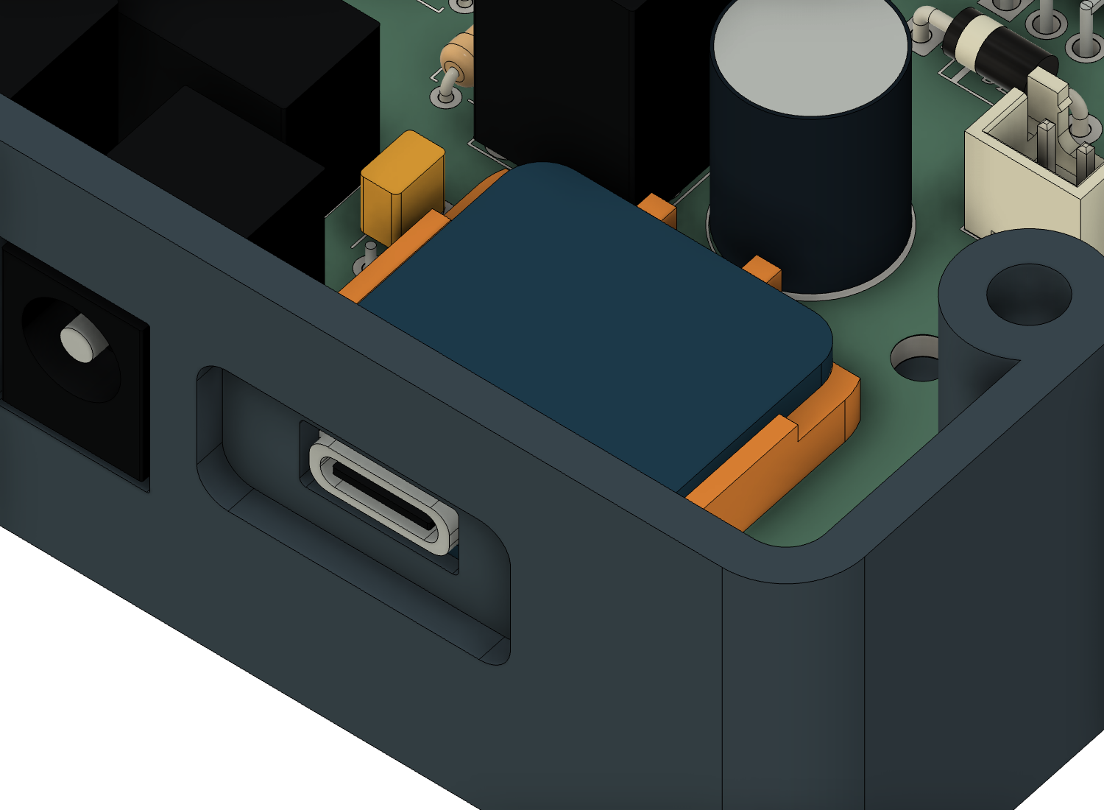
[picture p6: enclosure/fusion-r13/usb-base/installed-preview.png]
Base installed in the unchanged case


## Evidence and remaining check

The geometry uses the [official Adafruit PCB source](https://github.com/adafruit/Adafruit-USB-Type-C-Power-Delivery-Dummy-Breakout-PCB),
locally `work/pcb-draft/adafruit-5807-husb238.brd`. Underside reliefs cover the
modeled header/output solder, USB shell stakes and locating pegs.
[Native checks](native-verification.json) pass eight seat/stop cases, six
module-descent positions, fourteen solder/peg envelopes and two screw shafts.
Native STL measurements also pass six hole, six bearing/floor and eight open-window
samples. The base's maximum sampled difference from its independent reference
is 0.0022 mm. The seat height and existing case geometry are preserved.

**Physical fit of the new base remains to be checked**, including the actual
board, solder, wires and clamp grip. The images are CAD previews; these checks
do not establish extraction force, material creep or a heat rating.

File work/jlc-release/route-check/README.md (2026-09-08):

# Actual routed verification

**Routed engineering prototype; physical qualification remains.**

- Logical schematic checks: 104 pin/net pairs agree with the design description.
- PCB: 37 electrical footprints agree with those logical net assignments.
- J8: 10-pin socket for the user-linked blue module; physical fit not yet verified.
- U2: Traco TSR 2-2450N fixed 5 V / 2 A SIP-3; pinout, body envelope and coordinates checked independently.
- Q1: horizontal TO-220 body, G/D/S lead row, 1.4 mm drills and F.Cu live-tab keepout checked. 6.5 mm fitted envelope includes 1 mm insulating support; forming and thermal sample checks remain.
- K1 automatically selects wall power when energized, USB-PD otherwise. JP2 is removed. Eighteen jack/relay/source cases checked for source shorts and simultaneous input paths. Transfer timing, inrush and brownout require physical validation.
- Simplification: D1, C5, C7, C13, R17 and R18 are absent by assertion, along with the previously removed F1-F4/Q3/R7/R19.
- Protection: use only protected/current-limited regulated 12 V sources rated no more than 3 A; there is no onboard or branch-selective overcurrent protection.
- ADC module release gate: confirm local supply bypassing and SDA/SCL pull-ups to VDD before assembly.
- BZ1: direct GPIO14 drive through R6 330 ohm; Q3, R7 and R19 are absent by assertion. Test 4 kHz audibility in the enclosure.
- Adafruit 5807 HUSB238: official 20.32 x 23.495 mm PCB outline and two-hole pattern applied.
- 5807 mounting: 2.4 mm NPTH holes at [(36.753, 87.817), (51.993, 87.817)]; USB-C face is 0.500 mm inside the carrier power edge.
- 5807 mounting: F.Cu/B.Cu track/via/pour keepout present; no electrical-component or carrier-hole courtyard intersects the reserved region.
- Native KiCad ERC: 0 violations. This does not verify module hardware or performance.
- Native PCB/schematic parity: 0 issues. BOM manufacturer and DigiKey identifiers agree for 37 references.
- Native KiCad DRC: 0 reported violations plus 0 unconnected items.
- Copper routing: 314 track/arc segments, 16 vias, 1589.925 mm total segment length.
- Native DRC requires zero unconnected items. Planned power-trunk widths are present; narrower pad escapes and low-current branches are reported individually in summary.json for review.
- Four F.Cu top-washer keepouts cover Ø7.4 mm; circular NPTH exemptions stay within 1.7 mm radius. Underside boss exemptions are checked against the same limit.
- J2: 1.5 A/contact. Pin 4 carries combined blower and servo return; validate actual load, cable drop and contact heating.
- Four 3.2 mm NPTH M3 carrier mounts, 51 x 58 mm pattern; independently fastened to the bottom. WT32 mounts separately to the top via its retainer.

| Power net | Tracks | Total length, mm | Width: length, mm |
|---|---:|---:|---|
| PD_12V | 5 | 21.580 | 2: 21.580 |
| WALL_12V | 17 | 80.020 | 2: 80.020 |
| +12V | 16 | 119.770 | 0.3: 62.071, 2: 57.699 |
| FAN_OUT | 16 | 81.637 | 1.2: 81.637 |
| +5V | 37 | 153.167 | 1.2: 153.167 |
| +5V_WT32 | 5 | 50.461 | 1.2: 50.461 |

Ground zones are measured from actual saved fills:

- GND_FRONT / F.Cu: 3 filled regions, 3071.443 mm².
- GND_BACK / B.Cu: 4 filled regions, 2849.187 mm².
- Ground geometry: J1/J9/U2/C1/C3/D2 remain connected through regions surviving the 2 mm corridor check, joining layers at power-section PTH pads or GND vias. J2's combined blower/servo return also reaches that network at 1.2 mm corridor width. ADC/DEBUG pads are excluded as power-return layer bridges. A 0.01 mm width allowance avoids collapsing exactly nominal-width tracks to zero-area lines; short pad landings are allowed within the erosion distance + 0.05 mm. This checks geometry, not copper temperature, current sharing, PTH/via resistance or voltage drop.

PCB SHA-256: `ad0ad42e490f2b99894505aeef91572deda87427d5cea64148409fd53ec4bd97`.

Normalized native schematic pin-map SHA-256: `80ddba3ff031a202070c9084cdbf1d001501f4fd21a33c752aad2997ba2095a9`.

Reports are retained without exclusions. Resolve actual violations and all README
release gates before ordering. No electrical load, temperature, antenna, or physical
fit test has been performed.

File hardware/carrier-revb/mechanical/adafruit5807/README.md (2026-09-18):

# Adafruit 5807 direct carrier mount

The active Rev B-T2F0-A5807-S4 design mounts the Adafruit 5807 HUSB238 breakout
above the carrier at its power short end using a
[printed base](../../../../enclosure/fusion-r13/usb-base/README.md). The base
replaces both nylon spacers and the adhesive rear support while preserving the
3 mm module seating height and existing M2 mounting hardware.
The carrier mounts independently in the bottom shell on a 51 × 58 mm M3
pattern; the WT32 belongs to the top assembly. See the
[current enclosure fit prototype](../../../../enclosure/fusion-r13/README.md).

The geometry in `interface.json` is transcribed from Adafruit's published Eagle
board file:

- module PCB outline: 20.32 x 23.495 mm;
- two 2.5 mm plated module holes, 15.24 mm center-to-center;
- carrier hole centers: H5 = (36.753, 87.817) mm and H6 = (51.993, 87.817) mm;
- module envelope: X = 34.340–54.660 mm, Y = 66.862–90.357 mm;
- module PCB front edge is 1.643 mm inside carrier Y = 92.000 mm;
- USB-C connector face at (44.500, 91.500) mm: 1.143 mm beyond the module
  PCB and **0.500 mm inside the carrier edge**;
- Ø5 mm maximum M2 hardware uses a Ø5.3 mm reserved PCB footprint envelope.

Coordinates are relative to the carrier's upper-left board corner in the KiCad
layout view. The carrier remains shifted 4.5 mm toward the power end. The
existing socket position is 2 mm behind the exterior,
level with the floor of a 2 mm-deep, 20 × 10 mm outside recess. Its fitted
10.14 × 4.7 mm r7 opening clears the declared metal shell, thickness/spacer
allowances and installation lift; the cable
housing sits in the exterior recess. The module PCB clears the normal inner
wall by 0.643 mm and its reserved mounting envelope by 0.533 mm. The pocket's
integral internal backing has blind PCB/spacer/head clearances, retaining at least
0.943 mm of plastic locally. No board/hardware cutouts reach the outside.
The H5/H6 drill edges retain 2.983 mm to the carrier power edge. Verify the actual
cable boot, plug seating and new base stack during installation. Earlier
perfboard case SCAD/STLs are
legacy files and do not fit this carrier.

## Hardware stack

Install each fastener from the module side as:

```text
M2 screw head -> washer -> 5807 -> printed base (3 mm total seat) -> carrier -> washer -> M2 nut
```

Use the existing M2 screws and ordinary nuts, screw heads no larger than Ø4 mm
and washers no larger than Ø5 mm. The base has Ø2.4 mm holes on the unchanged,
asymmetric 15.24 mm pitch. Its 0.8 mm floor is included in the 3 mm seat;
do not add the old spacers or adhesive support. Keep the combined head and washer height above the module PCB at
most 2 mm, within the enclosure's reserved clearance. Verify the underside stack
height before substituting locking nuts or other hardware.
M2 x 10 mm screws are a starting length, not a released specification. Verify
thread engagement and clearance to the WT32 before purchasing a production
quantity. The printed perimeter bearing and rear support replace the former
separate rear support. Rear stops resist insertion; the two M2 clamps carry
extraction. The small front/corner guides are not a strong extraction stop.

Do not install a terminal block under the module. Solder a short red/black
20–22 AWG pair from V+/GND to the J1 harness, routing over the module's top
through the **5.1 mm gap between the rear stops** (Eagle u=7.8…12.9 mm). Do not
trap wires under the bearing surfaces. Secure and insulate the wire; it must
not carry USB insertion force. Trim solder tails to at most **2.5 mm below the
module underside**, leaving 0.5 mm above the carrier. The underside windows
clear the modeled PTH solder, USB shell stakes and locating pegs; inspect the
actual solder before tightening the board flat onto its seat.

The base prints flat without supports, in the same PETG/HT-PLA process used for
the case. The original four case parts have unchanged geometry and need no
reprint. The new base's physical fit remains to be checked.

The breakout ships in its 5 V / 1 A configuration. Following Adafruit's guide,
open the 5 V selection and bridge the 12 V and 3 A selections; do not leave two
voltage selections bridged. Perform this before connecting J1, then verify
voltage and polarity with a meter. J1 feeds `PD_12V` into K1's normally closed
contact. Raw wall input energizes K1 and selects the wall adapter instead.
JP2 is removed; no internal adjustment is needed. J9's normally closed sleeve
contact (pin 3) remains unused. A supply change can briefly restart the controller.
The carrier remains fuse-free and is intended only for protected/current-limited
regulated 12 V sources rated no more than 3 A.

## Reproduce the mechanical interface

From `hardware/carrier-revb`, using KiCad 9 Python:

```sh
python3 tools/export_enclosure_interface.py
```

This reads the existing routed PCB without rebuilding it. Do not run the draft
board generator merely to refresh the enclosure interface. Export after any
intentional placement change so the case uses the current mounts and socket faces. These checks do not replace physical cable, screw-stack or enclosure
fit testing.

Sources:

- [Adafruit 5807 product](https://www.adafruit.com/product/5807)
- [Adafruit HUSB238 guide](https://learn.adafruit.com/adafruit-husb238-usb-type-c-power-delivery-breakout)
- [Adafruit published PCB source](https://github.com/adafruit/Adafruit-USB-Type-C-Power-Delivery-Dummy-Breakout-PCB)

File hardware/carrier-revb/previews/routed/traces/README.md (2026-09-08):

Ground pours are omitted in these two review views to make the routed traces readable. The back view includes component reference labels as a review overlay; the main PCB has no such back silkscreen.

Use the filled front and back copper plots one directory above as the authoritative layer previews. These files were exported from temporary copies and do not change the PCB.

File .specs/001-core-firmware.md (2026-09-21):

# 001: Core Firmware Platform

**Branch**: `feature/mvp-scaffold`
**Created**: 2026-02-18
**Status**: Implemented

## Summary

The foundational firmware layer for the BBQ temperature controller. Implements PID-controlled fan and servo damper output, thermistor temperature reading via ADS1115 ADC, alarm detection with buzzer, error monitoring, cook session logging with power-loss recovery, persistent JSON configuration, WiFi provisioning with captive portal, and OTA firmware updates.

## Requirements

- PID controller with lid-open detection, bumpless transfer, and configurable tuning (P=4.0, I=0.02, D=5.0 defaults)
- Read 3 NTC thermistor probes (1 pit + 2 meat) via ADS1115 16-bit I2C ADC with Steinhart-Hart conversion
- EMA-filtered temperature readings (alpha=0.2) sampled at 1s intervals, PID computed every 4s
- PWM fan control (25 kHz) with kick-start (75% for 500ms), long-pulse mode below 10%, minimum 15% sustained speed
- Servo damper control (0-90 degree range, linear 0-100% mapping)
- Split-range fan+damper coordination: damper maps full PID range, fan activates above configurable threshold (default 30%)
- Pit band alarm (±15°F default, only after setpoint reached) and meat target alarms with hysteresis
- Buzzer alarm output (2 kHz tone, 500ms on/off pattern)
- Error detection: probe disconnect (ADC >= 32000), probe short (ADC <= 100), fire-out (2°F/min decline for 10+ min at 95%+ fan)
- Cook session logging: 13-byte data points at 5s intervals, 600-sample circular RAM buffer, LittleFS flush every 60s
- CSV and JSON export of session data
- Persistent configuration via config.json on LittleFS (WiFi, units, PID, fan, probes, alarms, setup state)
- Factory reset support (wipe config.json, restart setup wizard)
- WiFi provisioning via WiFiManager captive portal (AP: "BBQ-Setup" / "bbqsetup"), mDNS at bbq.local
- Auto-reconnect with exponential backoff (5s base, 60s max, 20 attempts)
- Fallback AP mode after 3 boot failures
- OTA firmware updates via ElegantOTA at /update endpoint, progress tracking, LittleFS preserved across updates
- Arduino setup/loop pattern with modular initialization and callback wiring

## Design

### Architecture

Modular design with each subsystem in its own .h/.cpp pair. The main loop orchestrates all modules via callbacks to avoid circular dependencies. Each module exposes a `begin()` for initialization and `update()` for periodic work.

### Control Loop (main.cpp)

```
setup():
  ConfigManager.begin() → load config.json
  TempManager.begin() → init ADS1115
  PidController.begin() → init QuickPID
  FanController.begin() → init LEDC PWM
  ServoController.begin() → attach servo
  AlarmManager.begin() → init buzzer pin
  ErrorManager.begin()
  CookSession.begin() → mount LittleFS, recover session
  WifiManager.begin() → connect or start AP
  OtaManager.begin() → register /update
  WebServer.begin() → start HTTP + WebSocket

loop():
  TempManager.update() → read ADC, convert temps
  PidController.update() → compute output
  FanController.setSpeed(pidOutput) → apply fan
  ServoController.setPosition(pidOutput) → apply damper
  AlarmManager.update() → check thresholds
  ErrorManager.update() → check errors
  CookSession.update() → log data point
  WebServer.update() → broadcast to clients
  WifiManager.update() → handle reconnection
  OtaManager.update() → service OTA
```

### PID Controller

Uses QuickPID library with pOnMeas, dOnMeas, and iAwCondition anti-windup. Lid-open detection arms after 30 seconds continuously within ±2% of setpoint, then triggers below 94% and recovers at 98%. A two-minute timeout, Resume now, disabling detection, a changed target or invalid probe clears the pause and requires fresh settling. PID history resets using the current measurement; the saved lid.enabled setting is shared by touchscreen and web controls.

### Temperature Pipeline

```
ADC raw → voltage divider → resistance → Steinhart-Hart → °C → optional °F → EMA filter
```

Steinhart-Hart coefficients from Thermoworks Pro-Series probes: A=7.3431401e-04, B=2.1574370e-04, C=9.5156860e-08. Reference resistor: 10K ohm (1% metal film). 0.1uF ceramic filter cap on each ADC input.

### Fan Control State Machine

1. **Off (0%)**: PWM=0
2. **Kick-start (0→non-zero)**: 75% duty for 500ms, then target
3. **Long-pulse (<10%)**: Cycle between 15% min and off over 10s period
4. **Normal (10-100%)**: Direct PWM with 15% floor

### Session Data Format

```c
struct DataPoint {  // 13 bytes
    uint32_t timestamp;   // UTC epoch seconds
    int16_t  pitTemp;     // °F × 10 (e.g., 2255 = 225.5°F)
    int16_t  meat1Temp;
    int16_t  meat2Temp;
    uint8_t  fanPct;
    uint8_t  damperPct;
    uint8_t  flags;       // bitmask: lid-open, alarms, errors, probe disconnects
};
```

### Configuration Persistence

All settings stored in `/config.json` on LittleFS via ArduinoJson. Structure mirrors the JSON schema documented in CLAUDE.md. Factory reset deletes the file and restarts.

## Files to Modify

| File | Change |
|---|---|
| `firmware/src/config.h` | Pin assignments, constants, defaults for all modules |
| `firmware/src/main.cpp` | Setup/loop orchestration, module init, callback wiring |
| `firmware/src/pid_controller.h/.cpp` | QuickPID wrapper with lid-open detection |
| `firmware/src/temp_manager.h/.cpp` | ADS1115 reading, Steinhart-Hart, EMA filtering |
| `firmware/src/fan_controller.h/.cpp` | PWM output, kick-start, long-pulse, min-speed |
| `firmware/src/servo_controller.h/.cpp` | Damper servo 0-90° control |
| `firmware/src/alarm_manager.h/.cpp` | Pit band + meat target alarms, buzzer |
| `firmware/src/error_manager.h/.cpp` | Probe disconnect/short, fire-out detection |
| `firmware/src/cook_session.h/.cpp` | Circular buffer, LittleFS persistence, CSV/JSON export |
| `firmware/src/config_manager.h/.cpp` | JSON config load/save, factory reset |
| `firmware/src/wifi_manager.h/.cpp` | WiFiManager captive portal, mDNS, auto-reconnect |
| `firmware/src/ota_manager.h/.cpp` | ElegantOTA integration |
| `firmware/platformio.ini` | Build configuration, library dependencies |

## Test Plan

- [x] PID controller computes correct output for given error (test_pid.cpp, 18 tests)
- [x] Lid-open detection triggers at 6% drop, recovers at 2% (test_pid.cpp)
- [x] Steinhart-Hart conversion matches known resistance/temperature pairs (test_temp_conversion.cpp, 22 tests)
- [x] Fan kick-start activates at 75% for 500ms on 0→non-zero transition (test_fan_logic.cpp, 20 tests)
- [x] Fan min-speed clamping at 15% (test_fan_logic.cpp)
- [x] Alarm triggers on pit deviation beyond band after setpoint reached (test_alarm.cpp, 32 tests)
- [x] Meat alarm triggers once at target, hysteresis prevents re-trigger (test_alarm.cpp)
- [x] Session circular buffer wraps correctly at 600 samples (test_session.cpp, 27 tests)
- [x] Session CSV/JSON export produces valid output (test_session.cpp)
- [x] Desktop tests pass (`pio test -e native`)
- [x] Firmware builds (`pio run -e wt32_sc01_plus`)

Manual lid pause: Open lid / Close lid controls on both UIs can start a bounded
pause without waiting for detection, including with detection Off. It ignores
warm readings and target changes; only Close/Resume or the original two-minute
deadline releases it. Repeated Open requests do not extend the deadline. Probe
faults continue to stop outputs independently. Missing meat probes are optional,
not errors; shorts and a missing/shorted pit probe remain faults.

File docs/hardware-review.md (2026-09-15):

# Hardware review — Rev B-T2F0-A5807-S4

The carrier is a **routed prototype** with a
[JLCPCB fabrication package](../hardware/carrier-revb/fabrication/jlcpcb-2026-09-06/README.md).
The order review corrected U2's undersized holes and misplaced body outline,
extended J9's slots to the fabricator's minimum aspect ratio, aligned J8's holes
with its socket drawing, and corrected manufacturing legend rules. Physical
module/enclosure fit and load qualification remain.
The [final electrical review](../hardware/carrier-revb/verification/final-electrical-review.md)
records the retained relay circuit and independent pin/polarity checks.
Three subagents reviewed electrical design, physical interfaces and firmware.
Findings were challenged against the actual KiCad netlist, manufacturer drawings
and production firmware before applying the small corrections below.

## Confirmed defects and corrections

| Priority | Defect | Correction |
|---|---|---|
| P1 | S2 put USB-PD on J9’s normally closed sleeve contact, shorting PD to ground with an empty jack. | Leave J9 pin 3 unused. K1 selects one positive source at a time, automatically giving powered wall input priority. |
| P1 | Probe conversion inverted the pull-up divider, treated ADC full scale as the excitation voltage, and never detected an open probe at 3.3 V. | Measure AIN3 each scan; use `R = 10000 * raw / (raw_supply - raw)` and a 98% rail-relative open threshold. Invalid reference readings invalidate the probes. |
| P1 | Losing the pit probe retained the old PID output and could keep the blower running. | Stop the fan and close the damper on invalid pit data. Resume only after a fresh valid PID computation. |
| P2 | The 25 kHz power PWM default was poorly suited to the passive MOSFET gate pull-up and uncharacterized two-wire blower. | Start at 100 Hz and a 100% kick-start; confirm startup, duty range and temperature on the actual blower. |
| P2 | The draft checker could return success with ERC/DRC violations and reuse stale reports. | Regenerate native reports, fail on actual violations and parity errors, and check all 18 jack/relay/source cases for source shorts and simultaneous input paths. |
| P2 | Final routing put a narrow return beside the servo signal at J2 pin 4. | Move the servo approach between layers and widen the shared ground escape to 1.2 mm; recheck filled-ground paths. |
| P2 | Mounting courtyards alone did not prohibit copper under metal washers. | Add top-washer copper keepouts and round the NPTH exemptions; preserve underside boss/sweep exclusions. |
| P2 | Existing controller enclosure instructions appeared applicable to the new carrier. | Mark the 50 × 70 mm perfboard case and controller STLs incompatible with the Rev B mounting and connector layout. |
| P2 | The first carrier case used an unsupported 8 mm WT32 rear mounting datum. | Use the Plus V1.3 drawing's 10.8 mm datum. The revised 44.9 mm case also lowers the carrier onto 5 mm posts and mounts Q1 flat. |

J9’s [manufacturer drawing](https://tensility.s3.us-west-2.amazonaws.com/imports/product_spec_sheets/54-00133.pdf)
shows A as the isolated center contact and B–C as the sleeve switch. The original
S2 1–3 assumption was also embedded in the verification script; clean ERC could
not establish the physical contact behavior. **Do not power S2 as drawn.**

The revised [wiring](wiring.md) and [carrier project](../hardware/carrier-revb/README.md)
use common ground with separate PD_12V and WALL_12V positive nets. K1 is a
G5Q-1 DC12 changeover relay: NC selects PD; a coil powered by raw WALL_12V selects
wall power through NO. D3 clamps the coil. JP2 is removed, so ordinary source
changes do not require opening the enclosure. An unpowered barrel plug does
not disable PD. The captured BOM is $29.21 before extras, $1.59 above S3.

The [Omron drawing and ratings](https://omronfs.omron.com/en_US/ecb/products/pdf/en-g5q.pdf)
specify NC 3 A/30 VDC, NO 5 A/30 VDC and a 0.4 W coil. Its transfer contact
opens before changing sources; switching can restart the controller. The flyback
diode slows release. This is a prototype source selector, with contact inrush,
brownout behavior and loaded transfer still requiring bench checks.

## Rebuttal decisions

- Keep the fixed TSR 2-2450N converter, common ground, high-side blower switch,
  flyback diode and direct passive-piezo drive. Their topology is consistent.
- Reject switching the PD negative return: external USB/PC grounds can bypass
  the disconnected return. No verified suitable switched-center jack was found.
- S4 used K1 to keep the sources exclusive. The subsequent
  [relay-free input review](../hardware/carrier-revb/power-input-review.md)
  compares a dual Schottky package and a low-loss electronic selector by cost,
  assembly and blower-voltage loss. The final user decision retains K1, with USB-PD on NC and wall on NO.
- Use the SPDT G5Q-1, not G5Q-1A: the latter has no normally closed contact.
  Account for the SPDT coil’s 0.4 W and NC contact’s lower 3 A rating.
- Keep the existing fuse-removal decision. Use protected/current-limited regulated
  12 V sources rated no more than 3 A; this carrier has no branch protection.
- Keep the ADS1115 module’s own bypassing and pull-ups as an assembly requirement.
  Extra carrier parts are not justified without evidence that those functions are missing.
- Do not treat a successful embedded compilation as working display hardware.
  The legacy TFT_eSPI SPI pins overlap carrier GPIO13/14. WT32’s actual parallel
  data bus spans two GPIO banks and its FT6336U touch uses I2C. Fixing pin flags
  alone does not fix the backend. See [firmware bring-up](../firmware/hardware-bringup.md).

The 100 Hz PWM default is a prototype starting point, supported by the
[Analog Devices two-wire fan discussion](https://www.analog.com/en/resources/technical-articles/fanspeed-regulators.html).
The exact fan still determines useful frequency, startup duration and duty range.

## Remaining physical work

1. Fit-check the purchased RJ45, probe jacks, barrel jack, converter, ADC socket
   and Adafruit 5807 mounting stack. Verify jack/cable electrical numbering.
2. Verify the owned ADC module’s local bypassing and SDA/SCL pull-ups to VDD.
   Measure DEBUG-derived 3.3 V with the display and Wi-Fi active.
3. Fit-check the new [landscape enclosure](../enclosure/fusion-r13/README.md), including
   WT32 antenna/rear components, blind-boss screw engagement and real plug bodies.
   The carrier now has an independent 51 × 58 mm M3 pattern; the WT32's
   51.39 × 75.14 mm pattern is on its internal retainer. Legacy controller STLs
   remain incompatible.
4. Complete the WT32 display/touch backend before testing with carrier loads.
5. Measure WT32 plus MG90S startup and loaded currents, 5 V droop, shared RJ45
   ground loading, blower startup/PWM and Q1/U2 temperatures. Begin servo travel
   with the linkage disconnected and conservative mechanical endpoints.
6. Validate the routed power copper against measured current and temperature.
   J2 pin 4 carries combined blower and servo return and is rated 1.5 A.
7. Rerun ERC/DRC/parity after routing, inspect Gerbers and PTH/NPTH drill output,
   and complete a representative multi-hour bench soak before cooker use.

## Bring-up checks

With sources disconnected, check J9 pins 2–3 are continuous only when empty and
pin 3 has no PCB connection elsewhere. Verify K1 coil pins 1/5, COM 2, NO 3 and
NC 4. With sources disconnected, check COM–NC continuity and diode polarity;
then exercise PD only, wall only, both, and an unpowered barrel plug with a
current-limited setup. Test interruption/restart, coil release and adapter
brownout before connecting the blower and servo.
Configure MOD1 for 12 V / 3 A and meter-check polarity before connecting loads.

Check U2’s 5 V output with a load before fitting JP1. Include all downstream
capacitance when checking its stated 820 uF capacitive-load limit. Its internal
current limiting protects the converter; it is not a precise 2 A branch fuse.
Remove JP1 before using the WT32’s own USB port.

Use known resistors on all three probe channels before temperature calibration.
Disconnect and short the pit channel during fan kick-start and each control mode:
the blower must stop and the damper close. Reconnection must wait for fresh control
data. Test fan and servo separately, then together; target 4.75–5.25 V on the 5 V
rail under the measured worst-case load.

See [generated verification](../hardware/carrier-revb/verification/README.md) for
actual CAD checks. Passing logical checks does not establish physical fit,
thermal performance or fabrication readiness.

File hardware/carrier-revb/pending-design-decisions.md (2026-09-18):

# Pending design decisions — Rev B-T2F0-A5807-S4

## Decisions implemented

- U2 is a Traco Power TSR 2-2450N fixed 5 V / 2 A SIP-3 converter.
- F1, F2, F3 and F4 are deleted. All four former protected branches are direct.
- JP1 stays as removable WT32 USB/carrier power isolation.
- Q3, R7 and R19 are deleted; GPIO14 drives BZ1 through R6 = 330 ohm.
- The ADS1115 uses the WT32 DEBUG 3.3 V rail; no 3.3 V LDO is fitted.
- MOD1 is the Adafruit 5807 HUSB238 breakout, directly mounted through H5/H6.
- Its printed base now replaces both nylon spacers and the adhesive rear
  support. The 3 mm total seat height and existing two M2 fasteners are retained;
  case and PCB geometry are unchanged.
- J9 is the Tensility 54-00133 barrel inlet. Its sleeve switch (pins 2–3) is
  unused; pin 1 feeds WALL_12V. K1 automatically selects wall power when its coil
  is energized, and PD otherwise. D3 suppresses the relay coil. JP2 is removed.
- D1, C5, C7, C13, R17 and R18 are deleted; the ADC module must provide local
  bypassing and SDA/SCL pull-ups to VDD.
- Q1 is IRF5305PBF, D2 is SB140, BZ1 is TDK PS1240P02BT, and R10-R12 are common
  10 k, 1% parts requiring per-channel calibration.

## Assumption attached to fuse removal

Only use protected/current-limited regulated 12 V sources rated no more than
3 A. Configure and verify MOD1 for a 12 V / 3 A request; use only a regulated
5.5 × 2.1 mm center-positive wall adapter at J9. K1 selects one positive input
at a time. The carrier intentionally provides no
branch-selective overcurrent protection. The TSR 2-2450N's internal protection
primarily protects the converter and does not establish safe current limits for
the MG90S, blower, RJ45 cable/contact or PCB traces.

## Physical bring-up and fit checks

1. Measure WT32 plus MG90S startup and loaded current on 5 V, including voltage
   droop and converter temperature in the intended enclosure.
2. Identify the exact blower current and verify Q1, D2, RJ45 contacts and shared
   return at startup and PWM operation.
3. Fit-check U2, RJ45, J9 and all three 2.5 mm jacks from real samples. Verify
   J9 pins 2–3 are continuous only with no barrel plug inserted. Pin 3 remains
   unconnected on the carrier; check K1 NC/NO continuity and both source states
   before powering loads. Verify source transfer/restart, coil release, contact
   inrush and brownout with the actual adapter and loads.
4. Confirm the owned ADS1115 pitch, edge offsets, insertion height, pull-ups and
   insulating support.
5. Fit-test the new [5807 printed base](../../enclosure/fusion-r13/usb-base/README.md)
   with the existing M2 hardware and actual USB cable. Confirm the 3 mm total
   seat, clamp retention, output-wire path and ≤2.5 mm underside solder tails.
   Verify screw, nut, connector and WT32 clearances. The original R13 case fit
   is confirmed; this new base remains physically unverified.
6. Confirm WT32 antenna and internal harness clearance in the assembled case.
7. Complete the WT32 display/touch driver integration described in
   `docs/hardware-review.md`; temperature conversion and provisional blower defaults
   are corrected, but embedded display/touch operation remains unverified.

This file records prototype decisions, not a safety certification.

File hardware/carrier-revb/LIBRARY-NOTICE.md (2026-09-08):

# KiCad library provenance

Standard device/transistor/power symbols in `PitClaw.kicad_sym` were extracted
from the installed KiCad 9.0.6 libraries. Inherited symbols were resolved and
project library identifiers were applied. Standard footprints embedded in the
PCB come from the installed KiCad footprint libraries; reference/annotation
placement was adjusted for this carrier. The RJ45 contact array began as an
adaptation of the related KiCad Amphenol RJHSE-5380 footprint. Its current
RJHSE5080 pin numbering, staggered contact locations, mounting pegs and body
offset were independently reconciled with Amphenol's
[P-RJHSE-X080 Rev A manufacturer drawing](https://cdn.amphenol-cs.com/media/wysiwyg/files/drawing/rjhsex080.pdf).
The drawing explicitly includes the RJHSE-5080 variant; this does not assert
interchangeability with a different RJ45 part or replace a first-article fit check.

Copyright: KiCad library contributors. The upstream library material is
licensed under [CC BY-SA 4.0](https://creativecommons.org/licenses/by-sa/4.0/legalcode),
with KiCad's electronic-design exception. See the complete
[KiCad library license and exception](https://www.kicad.org/libraries/license/)
and [upstream license document](https://gitlab.com/kicad/libraries/kicad-symbols/-/blob/master/LICENSE.md).
The corresponding adapted library material retains that license. No license
change is asserted for the user's other project files.

Sources: [KiCad symbols](https://gitlab.com/kicad/libraries/kicad-symbols),
[KiCad footprints](https://gitlab.com/kicad/libraries/kicad-footprints).
Project-specific connector geometry was transcribed from the sources identified
in README and remains subject to the stated engineering validation gates.

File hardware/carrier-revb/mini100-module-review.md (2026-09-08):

# Existing Mini100 converter — superseded listing review, 2026-09-04

> Historical only. Rev B-T2F0-A5807-S3 replaces the Mini100 and its socket/header with a
> soldered TSR 2-2450N and removes F1–F4. None of the recommendations below
> describe the current CAD/BOM.

Selected by the user: Weewooday, Amazon ASIN **B08JZ5FVLC**. This identifies the
listing, not a controlled manufacturer part number or a verified batch revision.

## Seller evidence

The [listing and seller photographs](https://www.amazon.com/dp/B08JZ5FVLC/)
describe a **20 × 11 × 5 mm** board with **2.54 mm** solder-hole pitch.
Looking at the component side with the pad row on the left, its top-to-bottom
labels are **EN, IN+, GND, VO+**. The underside view reverses that orientation.
Photographs show adjustable output with a cut-ADJ / solder-5V fixed-output option.

The advertised 3 A maximum requires additional cooling; the seller reports a
12 V input / 1.5 A output test without it. This is not a guaranteed continuous
rating in our enclosure. Input claims conflict: 4.5–12 V versus 4.5–24 V.
The description claims short-circuit protection but warns against sustained
shorts; it lists no output overvoltage protection. EN is described as default-on.

## User measurement and implemented B-M1S1 interface

The user confirmed **2.54 mm hole pitch** and **1.5 mm from the hole-row centres
to the nearest short PCB edge**. These replace the previous pitch/edge guesses.
The row is provisionally centered across the seller's 11 mm board width, leaving
1.69 mm between either outer pad centre and the adjacent long edge. That centering
has not been measured. Body dimensions remain seller data, not a new user measurement.

Retain this converter as the **prototype candidate** for the 5 V WT32/MG90S rail.
Do not attribute the superseded Traco's ratings or capacitor limit to it. The
blower remains on the separate 12 V path; it is not a load on this converter.

Implemented carrier connection: a four-position 2.54 mm through-hole header/socket
interface, with the module parallel to the carrier, components outward, and an
insulating support under its free end still to be fit-tested. U2 purchases a
Sullins PPPC041LFBN-RC socket. A separate Amphenol 68000-104HLF male header solders
to the module underside. The new local footprint uses 1.02 mm carrier drills
from the socket drawing; these are not a claim about the module's hole diameter.
Provide positive retention for transport; do not rely on a cantilevered socket
or an adhesive pad alone. Keep conductive hardware and carrier copper clear of
the exposed underside pads. Preserve access to the voltage-setting pads before
final assembly and leave ventilation around the switching parts.

EN should remain unconnected for the proposed always-on use after confirming
the actual module's behavior. Do not tie it to 12 V. Check the physical labels
against the assigned KiCad numbers before insertion; the order is orientation-specific.

The remaining physical checks are row centering, module-hole fit, PCB thickness,
underside protrusions and header seating. Nominal module underside height is
about 11.05 mm (socket plus male-header insulator), with approximately 16.05 mm
total above the carrier using the seller's 5 mm module height. These are fit-test
estimates, not verified stack dimensions. No mounting holes are assumed or
to be drilled into the module. A short-wire interface remains a fallback if its
holes do not accept the chosen header.

## Bring-up and protection

1. With the carrier and loads disconnected, verify the trigger's actual 12 V
   output. Identify and check converter polarity from its own silkscreen.
2. Set the converter to 5 V while unloaded, power-cycle, and measure again before
   attaching WT32 or MG90S. Any fixed-output modification is done unpowered and
   only after confirming the actual board matches the seller's instructions.
3. Use a current-limited bench supply and dummy load first. Check regulation,
   startup, temperature and recovery at the intended load. Avoid sustained shorts.
4. Test WT32 boot/Wi-Fi/backlight together with representative loaded servo
   movement. Scope the 5 V rail at WT32 and at the servo, including PTC and harness
   voltage drop. Do not accept a no-load multimeter reading as a transient test.
5. Repeat in the intended stack/enclosure at the expected ambient temperature.
   Stop on overheating, voltage excursions or resets; do not solve failures by
   blindly increasing fuse ratings or capacitance.

**Keep F1–F4 unchanged pending testing.** An advertised short-circuit feature is
not enough to justify deleting F2; the available information does not establish
safe fault coordination. F3's provisional 0.5 A hold value still needs evaluation
with the MG90S. Neither a PTC nor the input TVS is output overvoltage protection.

## Artifact status

Native CAD, previews, selection.json, XLSX and CSV now describe **B-M1S1**. U2's
symbol and footprint have four pins; pin 4 EN has a no-connect marker. Pin 1 OUT
is at (10.21,74.5), pin 2 GND at (7.67,74.5), pin 3 IN at (5.13,74.5), and pin 4
EN at (2.59,74.5), all in mm from the carrier's top-left component-side corner.
The 20 × 11 mm body is x=0.9–11.9, y=56–76. A switching-body copper keepout spans
x=0.4–12.4, y=55.5–72.5, leaving the pad row accessible for routing. Support and
retention geometry is not yet released; do not ship a cantilevered module.

C3, C5, F1, R5 and D2 moved in B-M1 without changing values or nets. B-M1S1
removes Q3, R7 and R19 for direct passive-piezo drive; no fuses, PD-module
dimensions or mounting holes changed. See the verification reports. This remains
an unrouted engineering draft, not an order.

Connector sources: [Sullins socket drawing](https://mm.digikey.com/Volume0/opasdata/d220001/medias/docus/937/Female_Headers.100_DS.pdf),
[Amphenol header](https://www.amphenol-cs.com/product/68000104hlf.html).

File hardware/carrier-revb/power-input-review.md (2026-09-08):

# Relay-free power input review

Reviewed 2026-09-06 against the S4 electrical design and r6 enclosure.
**Final decision: retain K1 and D3.** USB-PD connects to the normally closed
contact, wall power to normally open, and raw wall voltage powers the coil.
The user selected the relay after comparing blower-voltage loss, price and
assembly complexity. The schematic and routed PCB implement this choice.

The alternatives below are retained as comparison records. No diode ORing or
power-mux substitution is applied.

## Price and assembly comparison

DigiKey US prices checked 2026-09-06, quantities sufficient for one controller.
These are selector-circuit costs only; connectors, PD module, shared bulk
capacitor, PCB fabrication, assembly, shipping, tax and tariffs are excluded.
Small-passive budgets are estimates, not a completed purchasing selection.

| Option | Selector parts cost, USD | Complexity | Voltage drop at 1 A total input current |
|---|---:|---|---|
| Dual Schottky STPS10L40CT | $1.28 | One three-pin through-hole package; check flat mounting and heat | About 0.35–0.45 V; planning estimate |
| Existing G5Q-1 relay + SB140 | $2.03 | Two through-hole parts; straightforward assembly, bulky relay | Up to 0.10 V from initial specified contact resistance |
| Two separate SB540A diodes | $2.84 | Two axial through-hole parts; low height | About 0.3–0.5 V; planning estimate |
| TPS2121 + basic passives | About $3–$4 | Six-part basic circuit; tiny QFN requires suitable surface-mount assembly | 0.056 V typical, 0.070 V maximum at 25 °C |

The dual package saves $0.75 against the current relay circuit. Two separate
Vishay diodes are more expensive at the current single-board quantity. A
TPS2121 circuit adds roughly $1–$2 in components over the relay; its assembly
method is the larger practical difference.

Price sources: [ST dual diode](https://www.digikey.com/en/products/detail/stmicroelectronics/STPS10L40CT/1039594),
[G5Q-1 relay, $1.80](https://www.digikey.com/en/products/detail/aratas-america-llc/G5Q-1-DC12/355239),
[SB140, $0.23](https://www.digikey.com/en/products/detail/smc-diode-solutions/SB140/6022959),
[SB540A, $1.42 each](https://www.digikey.com/en/products/detail/vishay-general-semiconductor-diodes-division/SB540A-E3-54/2146218),
and [TPS2121RUXR, $2.44](https://www.digikey.com/en/products/detail/texas-instruments/TPS2121RUXR/9859001).

The [ST dual diode](https://www.st.com/resource/en/datasheet/stps10l40c.pdf)
contains two 5 A paths sharing a cathode. Only one diode drop is in the selected
path. Using its DC loss model gives about 0.36 W at 1 A and 1.22 W at 3 A;
temperature, mounting and actual waveforms still matter. Its exposed tab is
the common cathode, so a flat mount needs electrical clearance or insulation.

The [relay specification](https://omronfs.omron.com/en_US/ecb/products/pdf/en-g5q.pdf)
gives 100 mΩ maximum initial contact resistance. The table therefore uses a
maximum, not an invented typical value. Its 0.4 W coil loss is additional while
wall-powered; the coil is off on USB-only power.

The [TPS2121 datasheet](https://www.ti.com/lit/ds/symlink/tps2121.pdf) specifies
56 mΩ typical resistance: at 3 A, calculate 0.168 V drop and 0.504 W conduction
loss. Its 2 × 2.5 mm, 12-pad QFN needs reflow/hot-air or factory assembly.
The basic automatic circuit needs the IC, one current-limit resistor, three
local bypass capacitors and one soft-start capacitor. The $0.50–$1.50 passive
allowance produces the rounded $3–$4 budget. Wall-priority sensing adds two
resistors. Layout, input hotplug behavior and current-limit tolerance need
checking before this becomes an implemented design.

For the existing through-hole build, the relay remains a reasonable low-drop
choice. To remove the relay and retain nearly all blower voltage, TPS2121 is
the preferred candidate if surface-mount assembly is acceptable. The dual
diode is the simplest inexpensive choice when the voltage drop is acceptable.

## Diode option connections

| Connection | Proposed wiring |
|---|---|
| USB-PD | J1 pin 1 / PD_12V → first diode anode |
| Wall adapter | J9 pin 1 / WALL_12V → second diode anode |
| Main supply | Both banded cathodes → existing +12V load rail |
| Returns | Both input grounds remain connected to GND |
| Jack switch | J9 pin 3 stays unused |

Each diode must carry the entire input load by itself. The existing 1 A SB140
coil diode is not the proposed power diode. The dual STPS10L40CT above is the
lower-cost candidate; the previously researched separate part is Vishay
[SB540A](https://www.vishay.com/docs/88903/sb520a.pdf), a through-hole 5 A / 40 V
Schottky in DO-201AD. Its current rating depends on lead temperature and
mounting. Final purchasing choice and placement need a thermal check.

| Inputs | Expected normal behavior |
|---|---|
| USB only | USB supplies the load through its diode |
| Wall only | Wall supplies the load through its diode |
| Both | The higher effective voltage normally supplies most of the load; closely matched inputs may share |
| One powered, the other connected but unpowered | The other diode blocks substantial reverse feed into that input |

This is conventional [diode ORing, described by TI in section 3](https://www.ti.com/lit/an/slvae57b/slvae57b.pdf).
It does not guarantee wall priority. Connecting two adapters does not force
twice the normal current into the device: the load determines demand.

## Tradeoffs and rebuttal

Two independent reviews challenged source selection and searched for a jack
that could replace the relay mechanically. The earlier conclusion that possible
combined fault current required a relay was too restrictive for this prototype.

- **Keep source isolation.** Directly joining the positive inputs could feed a
  powered supply into a connected but unpowered adapter. Rare simultaneous use
  does not remove that case. Schottky diodes still have reverse leakage; they
  are not galvanic isolation.
- **Account for diode loss.** For the candidate, allow roughly 0.3–0.5 V drop
  over relevant operating currents. At an assumed 0.4 V and 1 A, dissipation is
  0.4 W; at 0.5 V and 3 A it is 1.5 W in the conducting diode. These are planning
  estimates, not measured temperatures. The regulated 5 V converter has ample
  input-voltage margin; check blower startup at the reduced supply voltage and
  diode temperature inside the enclosure.
- **Preserve the existing no-fuse prototype choice explicitly.** Diodes block
  reverse feed but do not limit total fault current. Two connected sources can
  both contribute to a short, so 3 A per adapter is not a 3 A system ceiling.
  A common fuse can be added after measuring startup/load current if that
  additional protection is wanted. Its time-current behavior must be matched
  to the wiring; it would not be an instantaneous 3 A clamp.
- **The jack switch still does not select positive power.** The current
  [Tensility drawing](https://tensility.s3.us-west-2.amazonaws.com/imports/product_spec_sheets/54-00133.pdf)
  switches the sleeve. Targeted alternatives from
  [Same Sky](https://www.sameskydevices.com/product/resource/pj-002ah.pdf),
  [Cliff](https://www.cliffuk.co.uk/products/dcconnectors/DualDCSockets.pdf) and
  [Switchcraft](https://www.switchcraft.com/assets/1/24/PC721A_CD_.pdf?6698=)
  also switch the sleeve. This was a targeted search, not proof that no suitable
  center-switched jack exists anywhere.

A low-loss power-mux IC addresses the blower-voltage concern with a modest
parts-cost increase, provided surface-mount assembly is acceptable. Separate
ideal-diode controllers and MOSFETs require at least two controller ICs and two
FETs; the controllers alone cost more than TPS2121, so that approach offers no
clear simplicity advantage here. Removing the relay does not itself justify
reducing case height: other component and display envelopes remain.

Before applying either proposal, finalize the selected option's parts and update
the schematic, PCB generator, source-state checks and BOM together. Then check
each source alone, both together, an unpowered connected adapter, cable hotplug,
blower startup and enclosed component temperature. No physical testing was
performed for this review.

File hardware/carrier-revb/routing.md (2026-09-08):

# Carrier routing — S4 relay prototype

The editable PCB is `pitclaw-carrier.kicad_pcb`. Keep its matching schematic,
project rules and local footprint libraries together. K1 retains USB-PD on NC,
wall power on NO and common ground. No electrical components were added by
the routing pass.

## Copper and placement

The board remains 60 × 92 mm, two layers, 1.6 mm FR-4, with a nominal 35 µm
(1 oz) external copper build assumption. This is a prototype layout, not a
measured temperature-rise or fabrication qualification.

| Path | Routing intent |
|---|---|
| PD_12V, WALL_12V and main +12V | 2.0 mm trunks; short pad escapes may neck down |
| +5V and WT32 +5V | 1.2 mm trunks; short pad escapes may neck down |
| FAN_OUT | 1.2 mm trunk |
| GPIO, probes, ADC and relay gate-bias branch | 0.3 mm minimum |
| Ground | Filled front and back copper, solid pad connections |
| Clearance | 0.3 mm copper spacing, 0.5 mm copper-to-edge minimum |
| Through vias | Minimum 0.8 mm diameter / 0.4 mm drill; power class 1.2 / 0.6 mm |

The narrow +12V branch feeds only R1's gate pull-up, about 12 mA with the
blower on; it is not the blower or regulator supply trunk. Ground pads use
solid connections for return width; they will need sufficient soldering heat.
See `verification/summary.json` for the actual width/length distributions and
track/via counts, including any short router neckdowns.

C2 moved to (15, 65) mm and C4 to (30.5, 70) mm, rotated 270°, to shorten the
regulator's bypass connections. All connector faces, mounting holes, Q1,
relay and module locations remain aligned with the r6 enclosure.

The final review widened J2's shared ground escape to 1.2 mm and moved the
adjacent servo signal through a via at (9, 80.6) mm. This removes the short
0.6–0.7 mm ground throat found after routing; the filled-ground review verifies
its connection to the broader power-return copper.

The JLCPCB review corrected U2's offset body and Ø1.4 mm lead drills, moving
its pin row to (17,70.75) mm. SERVO_SIG now takes a local left-side detour
outside the maximum converter body through two additional signal vias. Two
parallel Ø1.2/0.6 mm GND stitches at (18,78.5) and (20,78.5) mm preserve
the 2 mm main-return check. The original front WALL_12V trunk remains under a
1.54 mm edge strip of the maximum U2 body; keeping it there preserves the broad
back-layer return. This is a documented exception to Traco's under-body trace
guidance, not a claim of complete compliance. The final board has 314 tracks
and 16 vias.

Both copper layers preserve the Adafruit module reservation. The top avoids
Q1's live tab and the M3 washers; the bottom avoids the insert bosses and their
installation sweep, plus the two enclosure support ledges. Circular NPTH
exemptions in the mounting keepouts prevent square-corner copper pockets under
metal hardware. Component references and power labels are on front silkscreen.

## Verification and limits

`tools/check_draft.py` runs fresh native ERC, PCB DRC and schematic parity,
requires all nets connected, and checks source-selection topology, actual pin
assignments, BOM identifiers and mechanical reservations. The independent
review also examines the filled-ground geometry around the power returns; see
`verification/final-electrical-review.md` for its method and limits.

The wide traces do not increase connector or component ratings. J2 pin 4
carries the combined blower/servo return and is rated 1.5 A. Check the actual
blower's freewheel load against D2, the total WT32/servo load against U2's 2 A
rating, and temperature in the enclosure. Physical module fit, harness polarity,
source transfer and load testing remain as listed in the carrier README.

## Editing and reproduction

Schematic updates use `tools/build_draft.py --schematic-only`; this is also the
default and preserves the routed PCB. The explicit unrouted-board rebuild mode
refuses a board containing routed copper. For layout edits, open the native
KiCad PCB, refill zones and rerun verification. Do not replace it with an old
placement preview or an intermediate routing session.

Routing was performed locally with KiCad 9.0.6 and Freerouting 2.1.0, followed
by manual rule/keepout corrections, ground filling, cleanup and native KiCad
checks. Intermediate DSN/SES files are retained under `work/pcb-route` at the
repository root. They are investigation checkpoints, not the final PCB source.

The native layer exporter is `work/render_routed_previews.py` within this
carrier directory. Final SVG/PNG copper and assembly views are under
`previews/routed`; the back view is mirrored as viewed from the solder side.

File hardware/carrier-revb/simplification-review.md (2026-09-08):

# Simplification review — updated in Rev B-T2F0-A5807-S4

The carrier now contains only parts that serve a distinct electrical or
mechanical function. The requested simplifications are implemented in schematic,
PCB source, BOM and checks.

## DigiKey one-board cost change

| Change | Previous | S4 | Saving |
|---|---:|---:|---:|
| FQP27P06 -> IRF5305PBF | $3.99 | $2.53 | $1.46 |
| CPT-1255C-090 -> PS1240P02BT | $1.50 | $0.67 | $0.83 |
| 1N5819-TP -> SB140 | $0.31 | $0.23 | $0.08 |
| Precision R10-R12 plus R5 -> one common 1% line | $1.99 | $0.40 | $1.59 |
| Six Vishay 100 nF positions -> five TDK positions | $1.70 | $1.25 | $0.45 |
| C3 + C5 -> one 470 uF C3 | $0.55 | $0.52 | $0.03 |
| Remove D1 and C7 | $0.66 | $0.00 | $0.66 |
| Add 12 V wall-adapter inlet | $0.00 | $0.90 | -$0.90 |
| Automatic source relay K1 and coil diode D3 | $0.00 | $2.03 | -$2.03 |
| **Total BOM change** | **$31.38** | **$29.21** | **$2.17** |

Retained prices are the 2026-09-05 DigiKey US snapshot; K1 is from 2026-09-06.
See `bom/selection.json`. The S4 design has 37 populated electrical footprints versus 38 populated plus two DNP
footprints previously. A cheaper RECOM R-78K5.0-2.0 converter was reviewed but
not selected: its approximately $0.96 saving did not justify a taller or wider
right-angle mechanical envelope and a new placement risk in this stack.

| Change | Result |
|---|---|
| Mini100 module/socket/header | Replaced by one TSR 2-2450N THT converter. |
| F1 input PTC | Removed; K1 selects one protected/current-limited 12 V source at a time. |
| F2 WT32 PTC | Removed; +5 V reaches JP1 directly. |
| F3 servo PTC | Removed; +5 V reaches RJ45 pin 3 directly. |
| F4 blower PTC | Removed; Q1 drain reaches RJ45 pin 5 directly. |
| Q3/R7/R19 buzzer stage | Removed; GPIO14 drives passive BZ1 through R6. |
| Separate 3.3 V regulator | Not fitted; low-current ADC rail comes from WT32 DEBUG. |
| Source ORing diode | Not fitted; K1 selects PD by default and powered wall input automatically. J9's sleeve NC contact is unused. |
| D1 12 V TVS | Removed; HUSB238 output OVP acts first for the fixed 12 V request. |
| C3 + C5 bulk capacitors | Consolidated into one 470 uF C3. |
| ADC bypass and I2C pull-ups | Carrier C7/C13/R17/R18 removed; verify these functions on the owned module. |
| Q1 | FQP27P06 replaced by lower-cost IRF5305PBF with the same G-D-S pin order. |
| D2 | 1N5819-TP replaced by lower-cost SB140 with the same rating/package class. |
| BZ1 | Same Sky part replaced by lower-cost TDK PS1240P02BT passive piezo. |
| Probe bias | Common 10 k, 1% resistors replace 0.1% parts; calibrate each channel. |

Parts retained and why:

- Q1/Q2/R1/R2/R3 are the high-side 12 V blower switch and 3.3 V logic interface.
- D2 clamps blower inductive kick; it is not redundant overcurrent protection.
- C1/C2 and C3/C4 provide local rail decoupling for cable, converter, WT32 and
  MG90S load transients.
- R4/R5 establish a defined, protected servo control signal.
- Probe bias/filter components and AIN3 excitation measurement support accurate
  NTC readings in a noisy motor environment.
- JP1 prevents unverified back-powering when WT32 USB is connected.

The resulting fuse-free design depends on protected/current-limited regulated
12 V sources rated no more than 3 A and on test-verified wiring, trace widths,
connector loading and thermal performance. K1 avoids opening the case to change
sources and prevents normal parallel contribution from both sources. Verify relay
transfer/restart, inrush and brownout with the actual loads. J9's sleeve switch
must not be used as a positive-source selector. This is a deliberate prototype tradeoff, not an assertion that
the loads are independently protected.

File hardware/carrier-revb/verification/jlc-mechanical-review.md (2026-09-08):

# JLCPCB mechanical order review

Reviewed 2026-09-06. Scope: bare carrier PCB fabrication and its tolerance relationship to the r6 enclosure. This does not qualify a populated product or certify the purchased modules, plugs, screws, printed plastic, or thermal performance.

**Disposition: the corrected board outline, holes and mounting arrangement support a small bare-PCB prototype order. J9’s slot-length item is resolved. The r6 enclosure remains a nominal fit prototype and does not have a complete worst-case tolerance budget.**

## Current evidence

- The actual PCB has two copper layers and nominal 1.6 mm thickness. Edge.Cuts contains four connected straight segments defining exactly 60 × 92 mm. The board has square external corners, no rounded-corner specification, and no internal routed cutouts. The enclosure's rectangular PCB witness matches this outline.
- H1–H4 are Ø3.2 mm NPTH at (4.5, 4.5), (55.5, 4.5), (4.5, 62.5), (55.5, 62.5): a 51 × 58 mm mounting pattern. H5/H6 are Ø2.4 mm NPTH at (36.753, 87.817) and (51.993, 87.817). The remaining mechanical holes are the two Ø3.25 mm RJ45 pegs and three Ø1.2 mm probe-jack pegs.
- Existing native verification reports zero DRC violations, zero unconnected items and zero schematic-parity issues. The three enclosure collision checks pass at nominal dimensions. The top, bottom and retainer meshes each remain one connected watertight solid. These results do not include fabrication or printer variation.
- All source hashes recorded in `enclosure/review/verification.json` match the files inspected. The PCB hash is `7d648c85aaa1fabd4f39074680c3daeb83a75353a57960b03cd88eaad8274764`; case SCAD is `4f682c886fcae5e3fee92dca5948f43269c77ec7f5361b0e4be0aa3522276097`; generated interface SCAD is `dc19a718c7aa89431256124f31ea480d6a0e5973e2bcf92531672e36545f998b`. This review must be reconciled with any later CAD revision.

## Fabrication corrections verified

J9 pads 1–3 now have 0.8 × 1.6 mm plated oval drills, preserving their original centers and directions. This meets JLCPCB's 0.5 mm minimum plated-slot width and length-at-least-twice-width rule. The original Tensility pattern used 0.8 × 1.5 mm slots; extending only their length adds clearance. Probe slots remain 0.5 × 1.5 mm. [JLCPCB drilling capabilities](https://jlcpcb.com/capabilities/pcb-capabilities).

U2 now has Ø1.4 mm drills and Ø2.0 mm pads, corrected offset body geometry and anchor (17, 70.75) mm. J8 now has Ø1.05 mm drills. These values were read back independently from the final native PCB and agree with the companion footprint review. Native checks pass after the local routing repair.

The corrected U2 nominal body is X12.54–26.54, Y69.31–76.91 mm. Expanding it by 0.5 mm per edge keeps it clear of shell walls and closure columns. Independently reserving the full existing 16 mm fitted height at this actual location reaches Z25.1, below the top bezel's minimum Z25.6 and 3 mm below the display rear reserve. This conservative bound supplements the central SCAD component witness, which does not cover the full U2 body. The actual U2 pins are included in the regenerated underside sweep. See `enclosure/review/jlc-corrected-footprints.json` and the refreshed collision logs.

## Tolerance basis

Use ordinary CNC-routed individual boards for this case. JLCPCB lists ±0.2 mm regular routed dimensions, ±0.1 mm precision routing, ±0.4 mm V-scoring, ±10% thickness at 1.6 mm, and ±0.05 mm hole position. Its current through-hole diameter allowance is +0.13/−0.08 mm; its NPTH guide gives ±0.08 mm. These are fabrication capabilities, not measured results for this board. [Capability table](https://jlcpcb.com/capabilities/pcb-capabilities), [NPTH guide](https://jlcpcb.com/blog/npth-design-guide).

The following calculations apply those allowances to the current nominal model. Printer shrinkage, heat-set insert displacement, component seating, module-hole play and plug tolerances remain unmeasured. The published board-dimension tolerance alone is not a complete hole-to-outline datum specification.

| Interface | Current allowance | Consequence |
|---|---|---|
| Carrier blind edge channel | 60.4 mm wide, with 0.2 mm at each side; its end stops 0.2 mm beyond the nominal PCB power edge | A 0.2 mm outward edge deviation consumes the entire local clearance before print error or hole-to-edge registration. This is the main case-fit tolerance issue. It does not require changing the electrical PCB to order prototypes. Measure the delivered board and enlarge the hidden case channel if needed while preserving its exterior skin. |
| Channel height | Z7.2–9.7 mm; PCB underside seats at Z7.5; installation lift is 0.3 mm | At maximum 1.76 mm carrier thickness, the lifted PCB top is Z9.56, leaving 0.14 mm to the channel roof. Thickness variation alone fits; printed accuracy, bow and burrs still need checking. |
| Four M3 carrier mounts | Ø3.2 mm holes; Ø9 mm support bosses | A Ø3.12 mm minimum hole leaves only 0.06 mm radial space around an ideal Ø3 mm screw. Hole-position variation consumes most of that budget before insert placement error. The four fixed bosses are not a guaranteed production fit. Check an insert/mount coupon and do not force screws through a misaligned board. |
| M2 module mounts | Carrier holes Ø2.4 mm; purchased 5807 holes nominal Ø2.5 mm | A Ø2.32 mm carrier hole still clears an ideal Ø2 mm screw by 0.16 mm radially. However, the assembly is not a precision locating system: clearance at both boards can shift the USB face and hardware. Set the module against a fit fixture before tightening; its own manufacturing tolerance is not established by ordering this carrier from JLCPCB. |
| USB pocket and hidden reliefs | 20 × 10 mm exterior recess, 2 mm deep; 9.54 × 4.1 mm shell opening; 0.2 mm hidden PCB/head clearance | Nominal local floor skins are 0.943 mm at the PCB relief and 0.983 mm at the head relief. A +0.16 mm carrier thickness change alone consumes most of the hidden slot's 0.2 mm upward clearance, leaving 0.04 mm before module/spacer/print variation. Physical alignment and an actual cable fit are required. Do not present these thin regions as structurally tested. |
| RJ45 and barrel openings | Nominal faces flush; 0.3 mm profile clearance per side plus 0.3 mm installation travel | PCB thickness affects connector Z, while lead/peg tolerances and soldering affect face XY. Nominal flushness is not guaranteed by bare-board dimensional tolerance. Trial-seat connectors and plugs before committing to final plastic. |
| Initial carrier insertion | Lower at +0.5 mm Y, slide forward 4 mm, then lower 0.3 mm | Initial nominal end gaps are 1.0 mm at the probe noses and 1.5 mm at the power faces. This path is geometrically valid; the final fitted openings/channel are tighter than the initial lowering path. |
| Probe plug access | Ø10.5 mm openings; socket faces recessed 7.5 mm | Actual plug-body diameter, length and full seating remain a purchased-cable fit check. PCB milling tolerance does not establish plug reach. |

## Assembly limits retained

The underside CAD sweep uses all exported PTH pad/peg envelopes and a maximum 3 mm clipped solder-tail projection. M2 nut/washer/tip projection is limited to 3.3 mm below the carrier, with a Ø5 mm hardware envelope and 2 mm combined upper head/washer height. Inspect these dimensions on the assembled unit; a solder blob or substituted locking nut can invalidate the nominal path.

The final 16-via audit has 4.1144 mm minimum clearance to boss sweeps and 10.4632 mm to support sweeps. It assumes no protruding wire or solder mound on vias. Preserve the copper-free underside support patches and slide corridors. The relay's 16.2 mm seated envelope leaves 2.8 mm nominal reserve to the upper assembly; maximum carrier thickness alone reduces that to 2.64 mm, before unmeasured display, harness and printer variation.

For a small bare-board prototype run, the tight plastic interfaces are ordinary fit-development work. They prevent claiming a qualified enclosure or interchangeable assembled product. Keep the existing physical gates for the ADC module, actual WT32 rear envelope and mounting screws, cable seating, harness bends, and connector load testing. This review found no reason to add rounded PCB corners, change the 60 × 92 mm outline, or alter the mounting pattern merely to order the prototype boards.

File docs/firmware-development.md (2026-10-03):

# Firmware Development

Guide for building, flashing, testing, and understanding the Pit Claw firmware.

## Prerequisites

### Quick Setup (Windows)

```powershell
# Run from an elevated (Admin) PowerShell in the repo root
powershell -ExecutionPolicy Bypass -File scripts\setup-dev.ps1
```

This installs Git, Python, Node.js, PlatformIO CLI, and OpenSCAD. The script is idempotent — safe to run again anytime.

### Manual Install

If you prefer to install tools yourself (or you're not on Windows):

1. [Git](https://git-scm.com/)
2. [Python 3.12+](https://www.python.org/)
3. [PlatformIO CLI](https://docs.platformio.org/en/latest/core/installation.html) — `pip install platformio`
4. [VS Code](https://code.visualstudio.com/) + [PlatformIO extension](https://platformio.org/install/ide?install=vscode) (recommended)

## Build Commands

All commands run from the `firmware/` directory.

```bash
# Build firmware
pio run -e wt32_sc01_plus

# Flash firmware via USB
pio run -e wt32_sc01_plus --target upload

# Build simulator (desktop, no hardware needed)
pio run -e simulator

# Clean build artifacts
pio run --target clean

# Serial monitor
pio device monitor --baud 115200
```

## Testing

```bash
# Desktop unit tests (PID, prediction, alarms — no hardware)
pio test -e native

# Single test suite
pio test -e native --filter test_desktop/test_pid

# On-device integration tests (requires connected hardware)
pio test -e wt32_sc01_plus
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

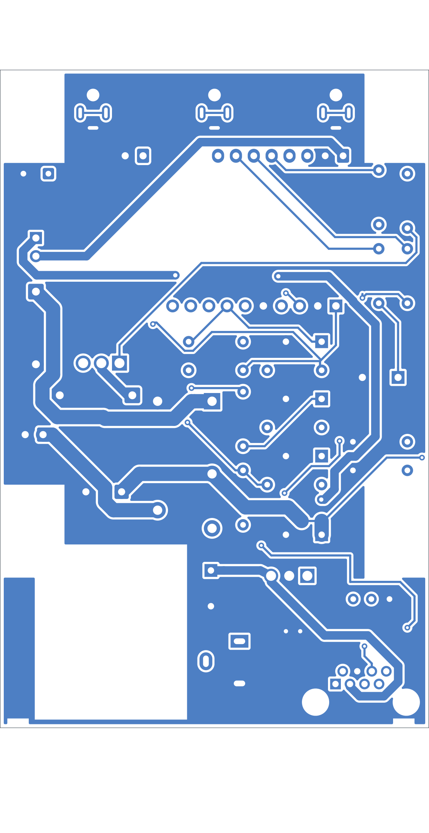
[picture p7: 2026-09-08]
hardware/carrier-revb/previews/routed/carrier-back-copper.png

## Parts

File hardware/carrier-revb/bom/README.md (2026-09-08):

# DigiKey prototype BOM — Rev B-T2F0-A5807-S4

The current BOM matches the fuse-free native CAD revision. U2 is the through-hole
**Traco Power TSR 2-2450N**, DigiKey **1951-TSR2-2450N-ND**, fixed 5 V / 2 A.
The Adafruit 5807 is included as a purchased, screw-mounted module. The Mini100,
its socket/header and F1–F4 are not purchased or fitted. J9 is the Tensility
54-00133 wall-adapter inlet. K1 automatically selects wall power when available,
and USB-PD otherwise. D3 is its coil flyback diode. JP2 and its shunt are removed;
J9's sleeve switch remains unused.

Retained DigiKey US public prices are from 2026-09-05; K1 was checked 2026-09-06. The simplified
one-carrier order subtotal is **$29.21** before shipping, tax or tariff:

| Scope | Subtotal |
|---|---:|
| Carrier parts plus Adafruit 5807 | $28.25 |
| Harness mates/contacts and JP1 shunt | $0.96 |
| Total | **$29.21** |

The workbook chooses price-break quantities when buying extra is cheaper.
Refresh price and stock before checkout; this snapshot is not a quote.

## Files

- `selection.json`: source of exact MPNs, DigiKey SKUs, price tiers, stock
  snapshots, descriptions and assembly cautions.
- `pitclaw-carrier-digikey-bom.xlsx`: editable order, detailed parts and unpriced
  assembly requirements.
- `pitclaw-carrier-digikey-import.csv`: initial 27-line DigiKey import file.

The CSV does not recalculate if workbook quantities are edited.

## Deliberate omissions and substitutions

- **F1–F4:** removed from schematic, PCB and BOM at the user's direction. Use
  only protected/current-limited regulated 12 V sources rated no more than 3 A.
  There is no onboard or branch-selective overcurrent protection.
- **Mini100:** replaced by the soldered TSR 2-2450N; no module socket or support
  is required.
- **Source selector:** K1 is G5Q-1 DC12 (Z221-ND), with an SB140 D3 across
  its raw-wall-powered coil. NC selects PD, NO selects wall, COM feeds +12V.
  NC is rated 3 A/30 VDC and NO 5 A/30 VDC; the coil draws approximately 0.4 W.
  Do not substitute the SPST G5Q-1A. Automatic transfer may restart the controller.
  The relay and D3 replace the JP2 header/shunt, adding $1.59 to S3.
- **Q3/R7/R19:** removed; BZ1 uses direct GPIO14 drive through R6.
- **D1:** removed because the Adafruit 5807/HUSB238 output OVP acts before the
  former P6KE18A's minimum breakdown for a 12 V request.
- **C5:** folded into one 470 uF C3. **C7/C13/R17/R18:** removed; confirm the
  owned ADS1115 module provides local bypassing and SDA/SCL pull-ups to VDD.
- **Q1:** IRF5305PBF replaces FQP27P06. **BZ1:** TDK PS1240P02BT replaces the
  Same Sky piezo. **D2:** SB140 replaces 1N5819-TP.
- **R10-R12:** common 10 k, 1% resistors replace 0.1% parts. Calibrate each probe
  channel; the calculated worst-case bias contribution is about 0.23–0.45 °C
  across 25–150 °C for a B≈3950 probe.

Converter short-circuit protection is not a precise 2 A branch limiter. The
datasheet's typical current-limit value for this model is 360% of rated load,
so actual wiring and loads still need bench testing.

## Not included in the subtotal

WT32-SC01 Plus, owned ADS1115, bare PCB, 5807 fasteners/support,
optional regulated 12 V / 3 A wall adapter, WT32-end harness connectors, wire,
crimp tooling, probes,
HeaterMeter blower/MG90S assembly, shipping, taxes and tariffs are excluded.

This is a purchasing aid for a routed engineering prototype, not authorization to
order the PCB.

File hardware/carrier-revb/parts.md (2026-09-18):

# Rev B-T2F0-A5807-S4 assembly parts

DigiKey selection checked 2026-09-05/06; see bom/ for priced purchasing lists.
Engineering draft, not fabrication approval.
U2 is the soldered TSR 2-2450N converter; J8 sockets the owned ADC module.
MOD1 is the screw-mounted Adafruit 5807 breakout and connects to J1 by a short
20-22 AWG power pair. J9 is the switched 5.5 x 2.1 mm, center-positive 12 V
barrel inlet. K1 automatically selects wall power when its raw 12 V coil is
energized; otherwise its normally closed contact selects USB PD. The SPDT
contacts select only one positive input at a time; grounds remain common.
J9 pin 3 is unused because its switch closes to sleeve/GND. D3 protects the
relay coil: banded cathode to WALL_12V, anode to GND. A source change can restart
the controller; verify switching and supply brownout behavior on the assembly.

| Ref | Value | Manufacturer part number | Footprint | Assembly |
|---|---|---|---|---|
| J1 | PD module output / 12V ONLY | B2B-XH-A | Connector_JST:JST_XH_B2B-XH-A_1x02_P2.50mm_Vertical | THT |
| J9 | 54-00133 / 12V CENTER + | 54-00133 | PitClaw:Tensility_54-00133_Horizontal | THT |
| K1 | G5Q-1 DC12 / WALL PRIORITY | G5Q-1 DC12 | PitClaw:Omron_G5Q1_SPDT_MaxBody | THT |
| D3 | SB140 / COIL FLYBACK | SB140 | Diode_THT:D_DO-41_SOD81_P10.16mm_Horizontal | THT |
| C1 | 470u / 35V | 35PX470MEFC10X12.5 | Capacitor_THT:CP_Radial_D10.0mm_P5.00mm | THT |
| C2 | 100n / 50V | FG28X7R1H104KNT06 | PitClaw:C_TDK_FG28X7R1H104KNT06_P5 | THT |
| U2 | TSR 2-2450N / 5V 2A | TSR 2-2450N | PitClaw:TRACO_TSR_2N_SIP3 | THT |
| C3 | 470u / 16V | 16ZLH470MEFC8X11.5 | Capacitor_THT:CP_Radial_D8.0mm_P3.50mm | THT |
| C4 | 100n / 50V | FG28X7R1H104KNT06 | PitClaw:C_TDK_FG28X7R1H104KNT06_P5 | THT |
| JP1 | REMOVE FOR WT32 USB | 68000-102HLF | Connector_PinHeader_2.54mm:PinHeader_1x02_P2.54mm_Vertical | THT |
| Q1 | IRF5305PBF | IRF5305PBF | PitClaw:IRF5305_TO220_Horizontal_TabDown | THT |
| R1 | 1k / 0.25W | MFR-25FBF52-1K | Resistor_THT:R_Axial_DIN0207_L6.3mm_D2.5mm_P7.62mm_Horizontal | THT |
| Q2 | 2N3904 | 2N3904BU | Package_TO_SOT_THT:TO-92_Inline_Wide | THT |
| R2 | 2.2k | MFR-25FBF52-2K2 | Resistor_THT:R_Axial_DIN0207_L6.3mm_D2.5mm_P7.62mm_Horizontal | THT |
| R3 | 100k | MFR-25FBF52-100K | Resistor_THT:R_Axial_DIN0207_L6.3mm_D2.5mm_P7.62mm_Horizontal | THT |
| D2 | SB140 | SB140 | Diode_THT:D_DO-41_SOD81_P10.16mm_Horizontal | THT |
| R4 | 220R | MFR-25FBF52-220R | Resistor_THT:R_Axial_DIN0207_L6.3mm_D2.5mm_P7.62mm_Horizontal | THT |
| R5 | 10k | MFR-25FBF52-10K | Resistor_THT:R_Axial_DIN0207_L6.3mm_D2.5mm_P7.62mm_Horizontal | THT |
| J2 | RJHSE-5080 / CHECK FOOTPRINT | RJHSE5080 | PitClaw:RJHSE-5080_DRAFT | THT |
| J3 | WT32 EXT harness | B8B-XH-A | Connector_JST:JST_XH_B8B-XH-A_1x08_P2.50mm_Vertical | THT |
| J7 | WT32 DEBUG 2 / 7 ONLY | B2B-XH-A | Connector_JST:JST_XH_B2B-XH-A_1x02_P2.50mm_Vertical | THT |
| BZ1 | PS1240P02BT / PIEZO | PS1240P02BT | PitClaw:Piezo_TDK_PS1240P02BT_D12.2_P5 | THT |
| R6 | 330R / PIEZO SERIES | MFR-25FBF52-330R | Resistor_THT:R_Axial_DIN0207_L6.3mm_D2.5mm_P7.62mm_Horizontal | THT |
| J4 | MJ1-2503A / PIT | MJ1-2503A | PitClaw:MJ1-2503A | THT |
| R10 | 10k / 1% | MFR-25FBF52-10K | Resistor_THT:R_Axial_DIN0207_L6.3mm_D2.5mm_P7.62mm_Horizontal | THT |
| R13 | 1k | MFR-25FBF52-1K | Resistor_THT:R_Axial_DIN0207_L6.3mm_D2.5mm_P7.62mm_Horizontal | THT |
| C10 | 100n / 50V | FG28X7R1H104KNT06 | PitClaw:C_TDK_FG28X7R1H104KNT06_P5 | THT |
| J5 | MJ1-2503A / MEAT 1 | MJ1-2503A | PitClaw:MJ1-2503A | THT |
| R11 | 10k / 1% | MFR-25FBF52-10K | Resistor_THT:R_Axial_DIN0207_L6.3mm_D2.5mm_P7.62mm_Horizontal | THT |
| R14 | 1k | MFR-25FBF52-1K | Resistor_THT:R_Axial_DIN0207_L6.3mm_D2.5mm_P7.62mm_Horizontal | THT |
| C11 | 100n / 50V | FG28X7R1H104KNT06 | PitClaw:C_TDK_FG28X7R1H104KNT06_P5 | THT |
| J6 | MJ1-2503A / MEAT 2 | MJ1-2503A | PitClaw:MJ1-2503A | THT |
| R12 | 10k / 1% | MFR-25FBF52-10K | Resistor_THT:R_Axial_DIN0207_L6.3mm_D2.5mm_P7.62mm_Horizontal | THT |
| R15 | 1k | MFR-25FBF52-1K | Resistor_THT:R_Axial_DIN0207_L6.3mm_D2.5mm_P7.62mm_Horizontal | THT |
| C12 | 100n / 50V | FG28X7R1H104KNT06 | PitClaw:C_TDK_FG28X7R1H104KNT06_P5 | THT |
| J8 | ADS1115 BLUE / 1x10 SOCKET | PPPC101LFBN-RC | PitClaw:ADS1115_Blue_1x10_DRAFT | THT |
| R16 | 1k | MFR-25FBF52-1K | Resistor_THT:R_Axial_DIN0207_L6.3mm_D2.5mm_P7.62mm_Horizontal | THT |

K1 uses the exact SPDT G5Q-1 DC12: pins 1/5 coil, 2 COM, 3 NO, 4 NC.
Reserve 16.2mm seated height, including its 0.4mm molded feet. Wall input
powers pin 1 and NO; pin 5 is GND, NC is PD_12V, COM is +12V.

Q1 mounts flat with the live drain tab downward. Form the leads before soldering;
use a 6mm body-to-pad-row distance, bend only beyond the widened 4.06mm lead
section, and use an inner bend radius of at least 0.8mm. Clamp/support the leads
between the bend and package; do not bend against the plastic body. Reserve
6.5mm seated height including a 1mm insulating under-body support. Cure small
electrically insulating, electronics-compatible adhesive support/side fillets
against a 1mm temporary spacing jig before soldering to retain Q1 for transport.
Remove the jig after curing. Do not install a tab bolt. Fit-check the lead form,
minimum under-body gap, adhesion and thermal behavior with the actual part.

Also required: WT32; owned blue 10-pin ADS1115; Adafruit 5807 MOD1; ADC
free-edge insulating support; insulating adhesive for Q1; one
[printed Adafruit 5807 base](../../enclosure/fusion-r13/usb-base/README.md);
2x M2x10 provisional screws, 4x M2 washers (5mm maximum OD) and 2x M2 nuts
under the carrier. The base replaces both 3mm nylon spacers and the adhesive
rear module support, with a total 3mm seat height; no extra screws or inserts
are required. Also supply harness mates, contacts, wire and one shunt for JP1;
4 M3 carrier screws into heat-set inserts in the bottom shell. WT32 mounts
separately inside the top bezel using an internal retainer and four small screws
matched to the WT32 rear blind bosses (diameter, thread and length require
sample verification). Enclosure closure uses separate M3 screws/inserts.
Confirm the owned ADC module has local bypassing and suitable SDA/SCL pull-ups
to VDD before assembly. Use only protected/current-limited regulated 12 V input
sources rated no more than 3 A; this revision has no onboard fuses. See
bom/README.md for assembly cautions.

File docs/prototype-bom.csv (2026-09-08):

Ref | Qty | Part | Minimum specification | Notes
MOD1 | 1 | Adafruit 5807 HUSB238 USB-C PD breakout | 12 V / 3 A request selected; use a compliant source/cable | Mount through H5/H6 on 3 mm nylon spacers; USB face projects 1.143 mm past carrier edge; connect V+/GND to J1
J9 | 1 | Tensility 54-00133 switched DC jack | 5.5 x 2.1 mm center-positive; 48 V 6 A; right-angle THT | Pin 1/A +12V, pin 2/B GND, pin 3/C PD_12V; empty passes PD and inserted plug selects wall adapter; do not hot-switch
U2 | 1 | Traco Power TSR 2-2450N | Fixed 5 V 2 A; 6.5-36 V input; SIP-3 THT | Pin 1 VIN, pin 2 GND, pin 3 VOUT; not a Mini100 footprint
U4 | 1 | Owned ADS1115 breakout | 3.3 V supply; 10-pin socketed module | Verify actual pitch/orientation/pull-ups and add free-edge support
Q1 | 1 | IRF5305PBF P-channel MOSFET | 55 V TO-220AB | High-side blower switch
Q2 | 1 | 2N3904 NPN transistor | TO-92 | Q1 gate driver
D2 | 1 | SB140 Schottky diode | 1 A 40 V DO-41 | Blower flyback clamp; cathode at FAN_OUT
R1 | 1 | 1 k ohm 1/4 W | 1% | Q1 gate-to-source pull-up
R2 | 1 | 2.2 k ohm 1/4 W | 1% | GPIO12 to Q2 base
R3 | 1 | 100 k ohm 1/4 W | 1% | Q2 base pull-down
R4 | 1 | 220 ohm 1/4 W | 1% | GPIO13 to servo signal
R5/R10-R12 | 4 | 10 k ohm 1/4 W | 1% | Servo pull-down and three calibrated probe-divider pull-ups
R6 | 1 | 330 ohm 1/4 W | 1% | GPIO14 to passive piezo
R13-R16 | 4 | 1 k ohm 1/4 W | 1% | ADC input series resistors including AIN3 rail measurement
C1 | 1 | 470 uF 35 V electrolytic | 105 C | 12 V bulk
C2/C4/C10-C12 | 5 | TDK FG28X7R1H104KNT06 | 100 nF 50 V X7R radial | Supply bypass and ADC filters
C3 | 1 | Rubycon 16ZLH470MEFC8X11.5 | 470 uF 16 V low-impedance 105 C | Consolidated 5 V bulk
BZ1 | 1 | TDK PS1240P02BT | Passive 3 V 4 kHz piezo | Direct GPIO14 drive through R6
J1/J7 | 2 | JST B2B-XH-A | 2-pin 2.50 mm THT | J1 is 12 V; J7 is 3.3 V; label to prevent interchange
J2 | 1 | Amphenol RJHSE5080 | 8P8C unmagnetized right-angle THT | HeaterMeter output; NOT ETHERNET
J3 | 1 | JST B8B-XH-A | 8-pin 2.50 mm THT | Carrier end of WT32 EXT harness
J4-J6 | 3 | Same Sky MJ1-2503A | 2.5 mm mono right-angle THT | Pin 1 sleeve; pins 2 and 3 tip
J8 | 1 | Sullins PPPC101LFBN-RC | 1x10 female 2.54 mm socket | For owned ADS1115 module
JP1 | 1 | 2-pin 2.54 mm header plus shunt | At least 1 A | Remove shunt for WT32 USB programming
PCB1 | 1 | Rev B-T2F0-A5807-S2 carrier | 60 x 92 mm two-layer FR-4 | Currently unrouted and not fabrication-ready

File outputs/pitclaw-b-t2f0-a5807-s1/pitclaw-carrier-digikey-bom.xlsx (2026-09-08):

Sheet: Order
Pit Claw carrier BOM
Rev B-T2F0-A5807-S1. One carrier with Adafruit 5807 and TSR 2-2450N. Checked 2026-09-05. USD.
Unrouted PCB: not for fabrication. Subtotal excludes PCB, mounting hardware and existing WT32/ADC.
Order quantities are editable (amber). Pricing follows the sampled breaks on Parts; refresh before checkout or larger builds.
References | Manufacturer part number | Needed | Order qty | Unit USD | Line USD | Spare qty | DigiKey part number | Source URL | Order note
U2 | TSR 2-2450N | 1 | 1 | $6.89000 | $6.89 | 0 | 1951-TSR2-2450N-ND | https://www.digikey.com/en/products/detail/traco-power/TSR-2-2450N/25903121 | Fitted carrier part. See Parts for specifications and assembly cautions.
J4, J5, J6 | MJ1-2503A | 3 | 3 | $0.77000 | $2.31 | 0 | CP1-2503AM-ND | https://www.digikey.com/en/products/detail/same-sky-formerly-cui-devices/MJ1-2503A/738679 | Fitted carrier part. See Parts for specifications and assembly cautions.
J2 | RJHSE5080 | 1 | 1 | $1.39000 | $1.39 | 0 | 664-RJHSE5080-ND | https://www.digikey.com/en/products/detail/amphenol-cs-commercial-products/RJHSE5080/1242687 | Fitted carrier part. See Parts for specifications and assembly cautions.
J1, J7 | B2B-XH-A | 2 | 2 | $0.10000 | $0.20 | 0 | 455-B2B-XH-A-ND | https://www.digikey.com/en/products/detail/jst-sales-america-inc/B2B-XH-A/1651045 | Fitted carrier part. See Parts for specifications and assembly cautions.
J3 | B8B-XH-A | 1 | 1 | $0.30000 | $0.30 | 0 | 455-B8B-XH-A-ND | https://www.digikey.com/en/products/detail/jst-sales-america-inc/B8B-XH-A/1651049 | Fitted carrier part. See Parts for specifications and assembly cautions.
J8 | PPPC101LFBN-RC | 1 | 1 | $0.66000 | $0.66 | 0 | S7043-ND | https://www.digikey.com/en/products/detail/sullins-connector-solutions/PPPC101LFBN-RC/810182 | Fitted carrier part. See Parts for specifications and assembly cautions.
JP1 | 68000-102HLF | 1 | 1 | $0.24000 | $0.24 | 0 | 609-3500-ND | https://www.digikey.com/en/products/detail/amphenol-cs-fci/68000-102HLF/1493545 | Fitted carrier part. See Parts for specifications and assembly cautions.
C1 | 35PX470MEFC10X12.5 | 1 | 1 | $0.66000 | $0.66 | 0 | 1189-1280-ND | https://www.digikey.com/en/products/detail/rubycon/35PX470MEFC10X12-5/3134236 | Fitted carrier part. See Parts for specifications and assembly cautions.
C3 | 16ZLH470MEFC8X11.5 | 1 | 1 | $0.52000 | $0.52 | 0 | 1189-1859-ND | https://www.digikey.com/en/products/detail/rubycon/16ZLH470MEFC8X11-5/3563382 | Fitted carrier part. See Parts for specifications and assembly cautions.
C2, C4, C10, C11, C12 | FG28X7R1H104KNT06 | 5 | 5 | $0.25000 | $1.25 | 0 | 445-173588-1-ND | https://www.digikey.com/en/products/detail/tdk/FG28X7R1H104KNT06/5803202 | Fitted carrier part. See Parts for specifications and assembly cautions.
D2 | SB140 | 1 | 1 | $0.23000 | $0.23 | 0 | 1655-SB140CT-ND | https://www.digikey.com/en/products/detail/smc-diode-solutions/SB140/6022959 | Fitted carrier part. See Parts for specifications and assembly cautions.
Q1 | IRF5305PBF | 1 | 1 | $2.53000 | $2.53 | 0 | IRF5305PBF-ND | https://www.digikey.com/en/products/detail/infineon-technologies/IRF5305PBF/811987 | Fitted carrier part. See Parts for specifications and assembly cautions.
Q2 | 2N3904BU | 1 | 1 | $0.29000 | $0.29 | 0 | 2N3904FS-ND | https://www.digikey.com/en/products/detail/onsemi/2N3904BU/1413 | Fitted carrier part. See Parts for specifications and assembly cautions.
BZ1 | PS1240P02BT | 1 | 1 | $0.67000 | $0.67 | 0 | 445-2525-1-ND | https://www.digikey.com/en/products/detail/tdk-corporation/PS1240P02BT/935930 | Fitted carrier part. See Parts for specifications and assembly cautions.
R1, R13, R14, R15, R16 | MFR-25FBF52-1K | 5 | 10 | $0.04200 | $0.42 | 5 | 1.00KXBK-ND | https://www.digikey.com/en/products/detail/yageo/MFR-25FBF52-1K/13011 | Price break makes this quantity cheaper than the exact need.
R2 | MFR-25FBF52-2K2 | 1 | 1 | $0.10000 | $0.10 | 0 | MFR-25FBF52-2K2-ND | https://www.digikey.com/en/products/detail/yageo/MFR-25FBF52-2K2/9138108 | Fitted carrier part. See Parts for specifications and assembly cautions.
R3 | MFR-25FBF52-100K | 1 | 1 | $0.10000 | $0.10 | 0 | 100KXBK-ND | https://www.digikey.com/en/products/detail/yageo/MFR-25FBF52-100K/13473 | Fitted carrier part. See Parts for specifications and assembly cautions.
R6 | MFR-25FBF52-330R | 1 | 1 | $0.11000 | $0.11 | 0 | MFR-25FBF52-330R-ND | https://www.digikey.com/en/products/detail/yageo/MFR-25FBF52-330R/9138136 | Fitted carrier part. See Parts for specifications and assembly cautions.
R4 | MFR-25FBF52-220R | 1 | 1 | $0.10000 | $0.10 | 0 | MFR-25FBF52-220R-ND | https://www.digikey.com/en/products/detail/yageo/MFR-25FBF52-220R/9138097 | Fitted carrier part. See Parts for specifications and assembly cautions.
R5, R10, R11, R12 | MFR-25FBF52-10K | 4 | 4 | $0.10000 | $0.40 | 0 | 10.0KXBK-ND | https://www.digikey.com/en/products/detail/yageo/MFR-25FBF52-10K/13219 | Fitted carrier part. See Parts for specifications and assembly cautions.
MOD1 | 5807 | 1 | 1 | $5.95000 | $5.95 | 0 | 1528-5807-ND | https://www.digikey.com/en/products/detail/adafruit-industries-llc/5807/21839778 | Screw-mounted module; configure 12 V / 3 A and meter-check before connection.
J1 mate, J7 mate | XHP-2 | 2 | 2 | $0.10000 | $0.20 | 0 | 455-2266-ND | https://www.digikey.com/en/products/detail/jst-sales-america-inc/XHP-2/555485 | J1 and J7 use different voltage rails; clearly label both ends.
J3 mate | XHP-8 | 1 | 1 | $0.11000 | $0.11 | 0 | 455-1902-ND | https://www.digikey.com/en/products/detail/jst-sales-america-inc/XHP-8/923773 | Carrier harness end only; separate WT32-end mate required.
XH harness contacts | BXH-001T-P0.6 | 11 | 11 | $0.05000 | $0.55 | 0 | BXH-001T-P0.6-ND | https://www.digikey.com/en/products/detail/jst-sales-america-inc/BXH-001T-P0-6/7423881 | 4 contacts for two 2-pin plugs + 7 for EXT; J3 pin 8 empty. Prefer 22 AWG for power. Loose contacts avoid 100-piece strip MOQ. Crimp tool/wire not included.
JP1 shunt | SPC02SYAN | 1 | 1 | $0.10000 | $0.10 | 0 | S9001-ND | https://www.digikey.com/en/products/detail/sullins-connector-solutions/SPC02SYAN/76375 | Remove for WT32 USB programming.
DigiKey parts subtotal |  |  |  |  | $26.28
Carrier parts plus MOD1 |  |  |  |  | $25.32
Mates and shunt |  |  |  |  | $0.96
Shipping, tax, tariffs, bare PCB, wire, crimp tools and unpriced items on Other items are excluded.
The CSV contains the initial 25 purchase lines. It does not update automatically when this workbook is edited.

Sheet: Parts
Part specifications and price breaks
Rev B-T2F0-A5807-S1. MOD1 is screw-mounted; U2 is fixed 5 V / 2 A; J8 sockets the owned ADC.
Package drawings guide selection. Physical sample fit and loaded/thermal testing remain required.
Price-break pairs start at I. Unit prices are a public snapshot, not a quote. Blank stock means not recorded.
References | Manufacturer | Part number | KiCad footprint | Assembly notes | Specification | Source URL | Stock | Qty 1 | Price 1 USD | Qty 2 | Price 2 USD | Qty 3 | Price 3 USD | Qty 4 | Price 4 USD | Qty 5 | Price 5 USD | State
U2 | Traco Power | TSR 2-2450N | PitClaw:TRACO_TSR_2N_SIP3 | Fixed-output converter; pin 1 VIN, 2 GND, 3 VOUT. Body 14 x 7.6 x 10.2 mm. Continuous short-circuit protection and automatic recovery; typical output current limit is 360% of rated output for this 5 V model. Maximum stated capacitive load is 820 uF. Verify all downstream capacitance, WT32/MG90S transients and enclosed temperature. | Fixed 5 V 2 A non-isolated switching regulator, 6.5-36 V input, SIP-3 THT | https://www.digikey.com/en/products/detail/traco-power/TSR-2-2450N/25903121 | 1046 | 1 | $6.89000 | 5 | $6.63200 | 10 | $6.52400 | 30 | $6.35733 | 50 | $6.28120 | Carrier
J4, J5, J6 | Same Sky | MJ1-2503A | PitClaw:MJ1-2503A | Keep for DigiKey build. Pin 1 sleeve; pins 2 and 3 both tip. PJ-210B is not a drop-in replacement. Check physical lead/slot fit. | 2.5 mm mono probe jack, right-angle THT | https://www.digikey.com/en/products/detail/same-sky-formerly-cui-devices/MJ1-2503A/738679 | 2366 | 1 | $0.77000 | 10 | $0.65700 | 25 | $0.61560 |  |  |  |  | Carrier
J2 | Amphenol ICC | RJHSE5080 | PitClaw:RJHSE-5080_DRAFT | Existing provisional pad geometry retained. Exact manufacturer drawing and sample fit remain release gates. Not an Ethernet/magnetics jack. | 8P8C right-angle unmagnetized RJ45, unshielded | https://www.digikey.com/en/products/detail/amphenol-cs-commercial-products/RJHSE5080/1242687 | 32472 | 1 | $1.39000 | 10 | $1.18300 | 25 | $1.10880 |  |  |  |  | Carrier
J1, J7 | JST | B2B-XH-A | Connector_JST:JST_XH_B2B-XH-A_1x02_P2.50mm_Vertical | Carrier side only. J1 is 12 V input; J7 is 3.3 V DEBUG. Same mate fits both: label/key harnesses and never interchange. | 2-pin XH vertical header, 2.50 mm pitch | https://www.digikey.com/en/products/detail/jst-sales-america-inc/B2B-XH-A/1651045 | 327189 | 1 | $0.10000 | 10 | $0.08700 | 100 | $0.07420 |  |  |  |  | Carrier
J3 | JST | B8B-XH-A | Connector_JST:JST_XH_B8B-XH-A_1x08_P2.50mm_Vertical | Carrier end of WT32 EXT harness; not the WT32's 1.25 mm connector. Pin 8 unused. | 8-pin XH vertical header, 2.50 mm pitch | https://www.digikey.com/en/products/detail/jst-sales-america-inc/B8B-XH-A/1651049 | 17894 | 1 | $0.30000 | 10 | $0.25700 | 250 | $0.20448 |  |  |  |  | Carrier
J8 | Sullins | PPPC101LFBN-RC | PitClaw:ADS1115_Blue_1x10_DRAFT | Socket only; ADC already owned. Confirm module pitch, edge offsets, insertion height and insulating support. | 1x10 female socket, 2.54 mm, 8.51 mm high | https://www.digikey.com/en/products/detail/sullins-connector-solutions/PPPC101LFBN-RC/810182 | 24709 | 1 | $0.66000 | 10 | $0.55900 | 100 | $0.47520 |  |  |  |  | Carrier
JP1 | Amphenol ICC | 68000-102HLF | Connector_PinHeader_2.54mm:PinHeader_1x02_P2.54mm_Vertical | Shunt ordered separately; remove shunt before powering WT32 from programming USB. | 1x2 male jumper header, 2.54 mm | https://www.digikey.com/en/products/detail/amphenol-cs-fci/68000-102HLF/1493545 | 103584 | 1 | $0.24000 | 10 | $0.20300 | 100 | $0.17260 |  |  |  |  | Carrier
C1 | Rubycon | 35PX470MEFC10X12.5 | Capacitor_THT:CP_Radial_D10.0mm_P5.00mm | 14 mm maximum seated height. 630 mA ripple at 10 kHz; verify actual input ripple and heating. | 470 uF 35 V, 105 C radial, D10 / P5 | https://www.digikey.com/en/products/detail/rubycon/35PX470MEFC10X12-5/3134236 | 64500 | 1 | $0.66000 | 10 | $0.41000 | 50 | $0.30500 |  |  |  |  | Carrier
C3 | Rubycon | 16ZLH470MEFC8X11.5 | Capacitor_THT:CP_Radial_D8.0mm_P3.50mm | Replaces C3 220 uF plus C5 100 uF with one 470 uF part. 13 mm maximum seated height; remains below U2's 820 uF stated maximum capacitive load before downstream capacitance is counted. | 470 uF 16 V, low-impedance 105 C radial, D8 / P3.5 | https://www.digikey.com/en/products/detail/rubycon/16ZLH470MEFC8X11-5/3563382 | 1853 | 1 | $0.52000 | 10 | $0.31800 | 50 | $0.23480 |  |  |  |  | Carrier
C2, C4, C10, C11, C12 | TDK | FG28X7R1H104KNT06 | PitClaw:C_TDK_FG28X7R1H104KNT06_P5 | 4 x 2.5 mm body, 5.5 mm maximum seated height and 5 mm formed-lead pitch. Carrier-level ADC-rail bypass C13 is removed because the socketed module must provide local bypassing. | 100 nF 50 V X7R 10%, radial MLCC, P5 | https://www.digikey.com/en/products/detail/tdk/FG28X7R1H104KNT06/5803202 | 72175 | 1 | $0.25000 | 10 | $0.14600 | 50 | $0.10480 | 100 | $0.09220 |  |  | Carrier
D2 | SMC Diode Solutions | SB140 | Diode_THT:D_DO-41_SOD81_P10.16mm_Horizontal | Stripe/cathode to FAN_OUT; verify clamp current against the actual blower. | 1 A 40 V Schottky diode, DO-41 | https://www.digikey.com/en/products/detail/smc-diode-solutions/SB140/6022959 | 38472 | 1 | $0.23000 | 10 | $0.13900 | 50 | $0.09940 |  |  |  |  | Carrier
Q1 | Infineon Technologies | IRF5305PBF | Package_TO_SOT_THT:TO-220-3_Vertical | Lower-cost active replacement for FQP27P06. Same TO-220 gate/drain/source pin order; 60 milliohm maximum at -10 V gate drive and live drain tab. Validate switching temperature with the actual blower and 25 kHz firmware PWM. | P-channel 55 V MOSFET, 31 A, TO-220AB | https://www.digikey.com/en/products/detail/infineon-technologies/IRF5305PBF/811987 | 18282 | 1 | $2.53000 | 10 | $1.62800 | 50 | $1.23600 |  |  |  |  | Carrier
Q2 | onsemi | 2N3904BU | Package_TO_SOT_THT:TO-92_Inline_Wide | Blower gate-driver transistor only. Form leads carefully to the wide-pitch THT footprint; do not reverse E/C. | NPN transistor, TO-92, 1E/2B/3C | https://www.digikey.com/en/products/detail/onsemi/2N3904BU/1413 | 165917 | 1 | $0.29000 | 10 | $0.17900 | 100 | $0.11130 |  |  |  |  | Carrier
BZ1 | TDK | PS1240P02BT | PitClaw:Piezo_TDK_PS1240P02BT_D12.2_P5 | Direct 3.3 V GPIO drive through R6 at 4 kHz; pin 2 to ground. 7.8 mm maximum seated height. Confirm useful audibility in the enclosure. | Passive piezo transducer, 3 V rated, 4 kHz, D12.2 / P5 | https://www.digikey.com/en/products/detail/tdk-corporation/PS1240P02BT/935930 | 44618 | 1 | $0.67000 | 10 | $0.50100 | 25 | $0.44920 |  |  |  |  | Carrier
R1, R13, R14, R15, R16 | YAGEO | MFR-25FBF52-1K | Resistor_THT:R_Axial_DIN0207_L6.3mm_D2.5mm_P7.62mm_Horizontal | R1 dissipates about 0.144 W at continuous fan-on. Buy ten for $0.42, less than five for $0.50. | 1 kOhm 1% metal film, 0.25 W, axial | https://www.digikey.com/en/products/detail/yageo/MFR-25FBF52-1K/13011 | 92700 | 1 | $0.10000 | 10 | $0.04200 | 25 | $0.03480 | 50 | $0.03040 | 100 | $0.02680 | Carrier
R2 | YAGEO | MFR-25FBF52-2K2 | Resistor_THT:R_Axial_DIN0207_L6.3mm_D2.5mm_P7.62mm_Horizontal | Blower transistor base resistor; 6.3 x 2.4 mm body and 7.62 mm formed lead pitch. | 2.2 kOhm 1% metal film, 0.25 W, axial | https://www.digikey.com/en/products/detail/yageo/MFR-25FBF52-2K2/9138108 | 18468 | 1 | $0.10000 | 10 | $0.04200 | 25 | $0.03480 | 50 | $0.03040 | 100 | $0.02680 | Carrier
R3 | YAGEO | MFR-25FBF52-100K | Resistor_THT:R_Axial_DIN0207_L6.3mm_D2.5mm_P7.62mm_Horizontal | Blower-transistor base pull-down. | 100 kOhm 1% metal film, 0.25 W, axial | https://www.digikey.com/en/products/detail/yageo/MFR-25FBF52-100K/13473 | 17481 | 1 | $0.10000 | 10 | $0.04200 | 25 | $0.03480 | 50 | $0.03040 | 100 | $0.02680 | Carrier
R6 | YAGEO | MFR-25FBF52-330R | Resistor_THT:R_Axial_DIN0207_L6.3mm_D2.5mm_P7.62mm_Horizontal | Direct-drive piezo series resistor. Limits the ideal initial 3.3 V capacitive-step current to 10 mA; 6.3 x 2.4 mm body and 7.62 mm formed lead pitch. Price checked 2026-09-05. | 330 Ohm 1% metal film, 0.25 W, axial | https://www.digikey.com/en/products/detail/yageo/MFR-25FBF52-330R/9138136 | 16985 | 1 | $0.11000 | 10 | $0.04400 | 25 | $0.03680 | 50 | $0.03240 | 100 | $0.02840 | Carrier
R4 | YAGEO | MFR-25FBF52-220R | Resistor_THT:R_Axial_DIN0207_L6.3mm_D2.5mm_P7.62mm_Horizontal | Servo signal series resistor. | 220 Ohm 1% metal film, 0.25 W, axial | https://www.digikey.com/en/products/detail/yageo/MFR-25FBF52-220R/9138097 | 23966 | 1 | $0.10000 | 10 | $0.04200 | 25 | $0.03480 | 50 | $0.03040 | 100 | $0.02680 | Carrier
R5, R10, R11, R12 | YAGEO | MFR-25FBF52-10K | Resistor_THT:R_Axial_DIN0207_L6.3mm_D2.5mm_P7.62mm_Horizontal | R5 is the servo pull-down; R10-R12 are probe bias resistors. Using common 1% parts trades roughly 0.2-0.5 C worst-case bias error across typical cooking temperatures for a large prototype cost reduction; calibrate each probe channel. | 10 kOhm 1% metal film, 0.25 W, axial | https://www.digikey.com/en/products/detail/yageo/MFR-25FBF52-10K/13219 | 126991 | 1 | $0.10000 | 10 | $0.04200 | 25 | $0.03480 | 50 | $0.03040 | 100 | $0.02680 | Carrier
MOD1 | Adafruit Industries | 5807 | Board-mounted module / 2 x M2 holes; wired to J1 | Board-mounted module. Configure and meter-check the 12 V / 3 A request before J1 connection. Official PCB outline is 20.32 x 23.495 mm with two 2.5 mm holes at 15.24 mm spacing. Mount over the carrier using M2 hardware and 3 mm insulating spacers; connect V+/GND to J1 with a short 20-22 AWG pair. | HUSB238 USB-C PD sink breakout; fixed-voltage jumpers; 5-20 V requests | https://www.digikey.com/en/products/detail/adafruit-industries-llc/5807/21839778 | 1682 | 1 | $5.95000 |  |  |  |  |  |  |  |  | Module
J1 mate, J7 mate | JST | XHP-2 | Off-board accessory | J1 and J7 use different voltage rails; clearly label both ends. | 2-pin XH cable housing | https://www.digikey.com/en/products/detail/jst-sales-america-inc/XHP-2/555485 |  | 1 | $0.10000 | 10 | $0.05900 | 25 | $0.05560 |  |  |  |  | Harness
J3 mate | JST | XHP-8 | Off-board accessory | Carrier harness end only; separate WT32-end mate required. | 8-pin XH cable housing | https://www.digikey.com/en/products/detail/jst-sales-america-inc/XHP-8/923773 |  | 1 | $0.11000 | 10 | $0.09500 | 25 | $0.08920 |  |  |  |  | Harness
XH harness contacts | JST | BXH-001T-P0.6 | Off-board accessory | 4 contacts for two 2-pin plugs + 7 for EXT; J3 pin 8 empty. Prefer 22 AWG for power. Loose contacts avoid 100-piece strip MOQ. Crimp tool/wire not included. | Loose crimp socket, 22-26 AWG | https://www.digikey.com/en/products/detail/jst-sales-america-inc/BXH-001T-P0-6/7423881 |  | 1 | $0.10000 | 10 | $0.05000 | 25 | $0.04680 | 50 | $0.04440 |  |  | Harness
JP1 shunt | Sullins | SPC02SYAN | Off-board accessory | Remove for WT32 USB programming. | Removable 2.54 mm shorting shunt | https://www.digikey.com/en/products/detail/sullins-connector-solutions/SPC02SYAN/76375 |  | 1 | $0.10000 | 10 | $0.02900 | 25 | $0.02720 |  |  |  |  | Harness

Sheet: Other items
Other assembly requirements
Not included in the DigiKey subtotal. Unknown quantities and prices are left blank, not assumed free.
5807 mounting hardware, cable clearance and WT32 stack lengths must be checked on the real assembly.
Item | Qty | Procurement | Assembly requirement
WT32-SC01 Plus | 1 | Existing display/controller | 51.39 × 75.14 mm mounting pattern confirmed. Absolute orientation, stack and antenna clearance still need checking.
ADS1115 blue 10-pin module | 1 | Already owned | VDD, GND, SCL, SDA, ADDR, ALRT, A0–A3. Confirm 2.54 mm pitch, module edge offsets, total socketed height, local supply bypassing, and SDA/SCL pull-ups to VDD.
Carrier bare PCB | 1 | Not yet orderable | 60 × 92 mm draft. Zero routed tracks. Resolve footprint, antenna, mechanical and load checks before routing and Gerber release.
M2 × 10 mm screws | 2 | Source locally / unpriced | Provisional 5807 fasteners. Verify the real module/spacer/carrier stack before buying a production quantity.
M2 washers, OD ≤5 mm | 4 | Source locally / unpriced | One under each screw head and one under each nut. Check clearance to module components.
M2 ordinary nuts | 2 | Source locally / unpriced | Install under the carrier PCB. Provide clearance to the WT32 and prevent contact with exposed circuitry.
3 mm nylon spacers | 2 | Source locally / unpriced | Between the Adafruit 5807 and carrier at H5/H6. Verify actual component-side and solder-joint clearance.
Adhesive insulating support | 1 | Source locally / unpriced | Support the rear/free edge of the 5807 at approximately 3 mm height; do not cover components or solder joints.
Unthreaded insulating WT32 spacers | 4 | Length not determined | Choose from actual rear components, trimmed leads and screw engagement. Do not assume a 10 mm length.
WT32 self-tapping screws, 2.3–2.5 mm | 4 | Length not determined | Engage existing WT32 mounts. Not M2/M3 machine screws; do not tap or enlarge the WT32 holes.
ADC insulating support | 1 | Geometry not determined | Support the socketed ADS1115 free edge and retain it for transport. Verify actual socket seating and underside protrusions. No guessed module mounting holes.
WT32-end EXT / DEBUG mates | 2 | Not included in DigiKey order | Confirm exact WT32 connector and mating cable. JST-XH BOM parts are only the carrier ends of these harnesses.
Hookup wire / insulation |  | As required; unpriced | Use a short 20-22 AWG red/black pair from 5807 V+/GND to J1. Label J1 separately from 3.3 V J7; their housings interchange physically.
Crimp tool and assembly supplies |  | Existing or source separately | Correct crimps, solder, insulation and strain relief required. Bare contact price excludes crimping labor/tool.
USB-C PD source and cable | 1 | Existing or source separately | Required design assumption: compliant 12 V USB-PD source and cable limited to 3 A. Configure MOD1 for 12 V / 3 A and confirm voltage/polarity with a meter.
HeaterMeter blower / MG90S / cable | 1 | Existing assembly | Measure startup/loaded motion and combined RJ45 return current. This revision intentionally has no onboard fuses or branch-selective overcurrent protection. Do not connect carrier RJ45 to Ethernet equipment.
2.5 mm NTC probes | 3 | Existing / up to three | PIT, MEAT 1, MEAT 2. Verify calibration and firmware excitation-reference equation before thermal testing.

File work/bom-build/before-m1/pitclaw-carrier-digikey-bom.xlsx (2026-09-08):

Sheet: Order
Pit Claw carrier BOM
Rev B-DK1. One carrier. DigiKey US price snapshot, 2026-09-04. USD.
Unrouted PCB: not for fabrication. Parts subtotal excludes existing modules, PCB and mounting hardware.
Order quantities are editable (amber). Pricing follows the sampled breaks on Parts; refresh before checkout or larger builds.
References | Manufacturer part number | Needed | Order qty | Unit USD | Line USD | Spare qty | DigiKey part number | Source URL | Order note
U2 | TSR 2-2450N | 1 | 1 | $6.89000 | $6.89 | 0 | 1951-TSR2-2450N-ND | https://www.digikey.com/en/products/detail/traco-power/TSR-2-2450N/25903121 | Fitted carrier part. See Parts for specifications and assembly cautions.
J4, J5, J6 | MJ1-2503A | 3 | 3 | $0.77000 | $2.31 | 0 | CP1-2503AM-ND | https://www.digikey.com/en/products/detail/same-sky-formerly-cui-devices/MJ1-2503A/738679 | Fitted carrier part. See Parts for specifications and assembly cautions.
J2 | RJHSE5080 | 1 | 1 | $1.39000 | $1.39 | 0 | 664-RJHSE5080-ND | https://www.digikey.com/en/products/detail/amphenol-cs-commercial-products/RJHSE5080/1242687 | Fitted carrier part. See Parts for specifications and assembly cautions.
J1, J7 | B2B-XH-A | 2 | 2 | $0.10000 | $0.20 | 0 | 455-B2B-XH-A-ND | https://www.digikey.com/en/products/detail/jst-sales-america-inc/B2B-XH-A/1651045 | Fitted carrier part. See Parts for specifications and assembly cautions.
J3 | B8B-XH-A | 1 | 1 | $0.30000 | $0.30 | 0 | 455-B8B-XH-A-ND | https://www.digikey.com/en/products/detail/jst-sales-america-inc/B8B-XH-A/1651049 | Fitted carrier part. See Parts for specifications and assembly cautions.
J8 | PPPC101LFBN-RC | 1 | 1 | $0.66000 | $0.66 | 0 | S7043-ND | https://www.digikey.com/en/products/detail/sullins-connector-solutions/PPPC101LFBN-RC/810182 | Fitted carrier part. See Parts for specifications and assembly cautions.
JP1 | 68000-102HLF | 1 | 1 | $0.24000 | $0.24 | 0 | 609-3500-ND | https://www.digikey.com/en/products/detail/amphenol-cs-fci/68000-102HLF/1493545 | Fitted carrier part. See Parts for specifications and assembly cautions.
F1 | MF-RHT200/32-2 | 1 | 1 | $0.73000 | $0.73 | 0 | 118-MF-RHT200/32-2CT-ND | https://www.digikey.com/en/products/detail/bourns-inc/MF-RHT200-32-2/7804098 | Fitted carrier part. See Parts for specifications and assembly cautions.
F2 | MF-R075 | 1 | 1 | $0.47000 | $0.47 | 0 | MF-R075-ND | https://www.digikey.com/en/products/detail/bourns-inc/MF-R075/259967 | Fitted carrier part. See Parts for specifications and assembly cautions.
F3, F4 | MF-R050 | 2 | 2 | $0.47000 | $0.94 | 0 | MF-R050-ND | https://www.digikey.com/en/products/detail/bourns-inc/MF-R050/259965 | Fitted carrier part. See Parts for specifications and assembly cautions.
C1 | 35PX470MEFC10X12.5 | 1 | 1 | $0.66000 | $0.66 | 0 | 1189-1280-ND | https://www.digikey.com/en/products/detail/rubycon/35PX470MEFC10X12-5/3134236 | Fitted carrier part. See Parts for specifications and assembly cautions.
C3 | 16ZLH220MEFCT16.3X11 | 1 | 1 | $0.31000 | $0.31 | 0 | 1189-4157-1-ND | https://www.digikey.com/en/products/detail/rubycon/16ZLH220MEFCT16-3X11/3568112 | Fitted carrier part. See Parts for specifications and assembly cautions.
C5 | 16ZLH100MEFC5X11 | 1 | 1 | $0.24000 | $0.24 | 0 | 1189-1148-ND | https://www.digikey.com/en/products/detail/rubycon/16ZLH100MEFC5X11/3134106 | Fitted carrier part. See Parts for specifications and assembly cautions.
C7 | 100YXJ4R7M5X11 | 1 | 1 | $0.23000 | $0.23 | 0 | 1189-1030-ND | https://www.digikey.com/en/products/detail/rubycon/100YXJ4R7M5X11/3133958 | Fitted carrier part. See Parts for specifications and assembly cautions.
C2, C4, C10, C11, C12, C13 | K104K15X7RF5TH5 | 6 | 10 | $0.17000 | $1.70 | 4 | BC1101CT-ND | https://www.digikey.com/en/products/detail/vishay-beyschlag-draloric-bc-components/K104K15X7RF5TH5/286723 | Price break makes this quantity cheaper than the exact need.
D1 | P6KE18A-TP | 1 | 1 | $0.43000 | $0.43 | 0 | P6KE18A-TPMSCT-ND | https://www.digikey.com/en/products/detail/mcc-micro-commercial-components/P6KE18A-TP/1959216 | Fitted carrier part. See Parts for specifications and assembly cautions.
D2 | 1N5819-TP | 1 | 1 | $0.31000 | $0.31 | 0 | 1N5819-TPCT-ND | https://www.digikey.com/en/products/detail/mcc-micro-commercial-components/1N5819-TP/950588 | Fitted carrier part. See Parts for specifications and assembly cautions.
Q1 | FQP27P06 | 1 | 1 | $3.99000 | $3.99 | 0 | FQP27P06-ND | https://www.digikey.com/en/products/detail/onsemi/FQP27P06/965349 | Fitted carrier part. See Parts for specifications and assembly cautions.
Q2, Q3 | 2N3904BU | 2 | 2 | $0.29000 | $0.58 | 0 | 2N3904FS-ND | https://www.digikey.com/en/products/detail/onsemi/2N3904BU/1413 | Fitted carrier part. See Parts for specifications and assembly cautions.
BZ1 | CPT-1255C-090 | 1 | 1 | $1.50000 | $1.50 | 0 | 102-3752-ND | https://www.digikey.com/en/products/detail/cui-inc/CPT-1255C-090/6012423 | Fitted carrier part. See Parts for specifications and assembly cautions.
R1, R13, R14, R15, R16, R19 | MFR-25FBF52-1K | 6 | 10 | $0.04200 | $0.42 | 4 | 1.00KXBK-ND | https://www.digikey.com/en/products/detail/yageo/MFR-25FBF52-1K/13011 | Price break makes this quantity cheaper than the exact need.
R2, R6 | MFR-25FBF52-2K2 | 2 | 2 | $0.10000 | $0.20 | 0 | MFR-25FBF52-2K2-ND | https://www.digikey.com/en/products/detail/yageo/MFR-25FBF52-2K2/9138108 | Fitted carrier part. See Parts for specifications and assembly cautions.
R3, R7 | MFR-25FBF52-100K | 2 | 2 | $0.10000 | $0.20 | 0 | 100KXBK-ND | https://www.digikey.com/en/products/detail/yageo/MFR-25FBF52-100K/13473 | Fitted carrier part. See Parts for specifications and assembly cautions.
R4 | MFR-25FBF52-220R | 1 | 1 | $0.10000 | $0.10 | 0 | MFR-25FBF52-220R-ND | https://www.digikey.com/en/products/detail/yageo/MFR-25FBF52-220R/9138097 | Fitted carrier part. See Parts for specifications and assembly cautions.
R5 | MFR-25FBF52-10K | 1 | 1 | $0.10000 | $0.10 | 0 | 10.0KXBK-ND | https://www.digikey.com/en/products/detail/yageo/MFR-25FBF52-10K/13219 | Fitted carrier part. See Parts for specifications and assembly cautions.
R10, R11, R12 | MFP-25BRD52-10K | 3 | 3 | $0.63000 | $1.89 | 0 | 10KADCT-ND | https://www.digikey.com/en/products/detail/yageo/MFP-25BRD52-10K/2058797 | Fitted carrier part. See Parts for specifications and assembly cautions.
R17, R18 | MFR-25FBF52-4K7 | 0 | 0 | $0.00000 | $0.00 | 0 | MFR-25FBF52-4K7-ND | https://www.digikey.com/en/products/detail/yageo/MFR-25FBF52-4K7/9138176 | DNP. Order only if module lacks suitable I2C pull-ups.
J1 mate, J7 mate | XHP-2 | 2 | 2 | $0.10000 | $0.20 | 0 | 455-2266-ND | https://www.digikey.com/en/products/detail/jst-sales-america-inc/XHP-2/555485 | J1 and J7 use different voltage rails; clearly label both ends.
J3 mate | XHP-8 | 1 | 1 | $0.11000 | $0.11 | 0 | 455-1902-ND | https://www.digikey.com/en/products/detail/jst-sales-america-inc/XHP-8/923773 | Carrier harness end only; separate WT32-end mate required.
XH harness contacts | BXH-001T-P0.6 | 11 | 11 | $0.05000 | $0.55 | 0 | BXH-001T-P0.6-ND | https://www.digikey.com/en/products/detail/jst-sales-america-inc/BXH-001T-P0-6/7423881 | 4 contacts for two 2-pin plugs + 7 for EXT; J3 pin 8 empty. Prefer 22 AWG for power. Loose contacts avoid 100-piece strip MOQ. Crimp tool/wire not included.
JP1 shunt | SPC02SYAN | 1 | 1 | $0.10000 | $0.10 | 0 | S9001-ND | https://www.digikey.com/en/products/detail/sullins-connector-solutions/SPC02SYAN/76375 | Remove for WT32 USB programming.
DigiKey parts subtotal |  |  |  |  | $27.95
Carrier parts only |  |  |  |  | $26.99
Harness and shunt |  |  |  |  | $0.96
Shipping, tax, tariffs, bare PCB, print material, wire, crimp tools and unpriced items on Other items are excluded.
The CSV contains the initial 30 purchase lines. It does not update automatically when this workbook is edited.
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

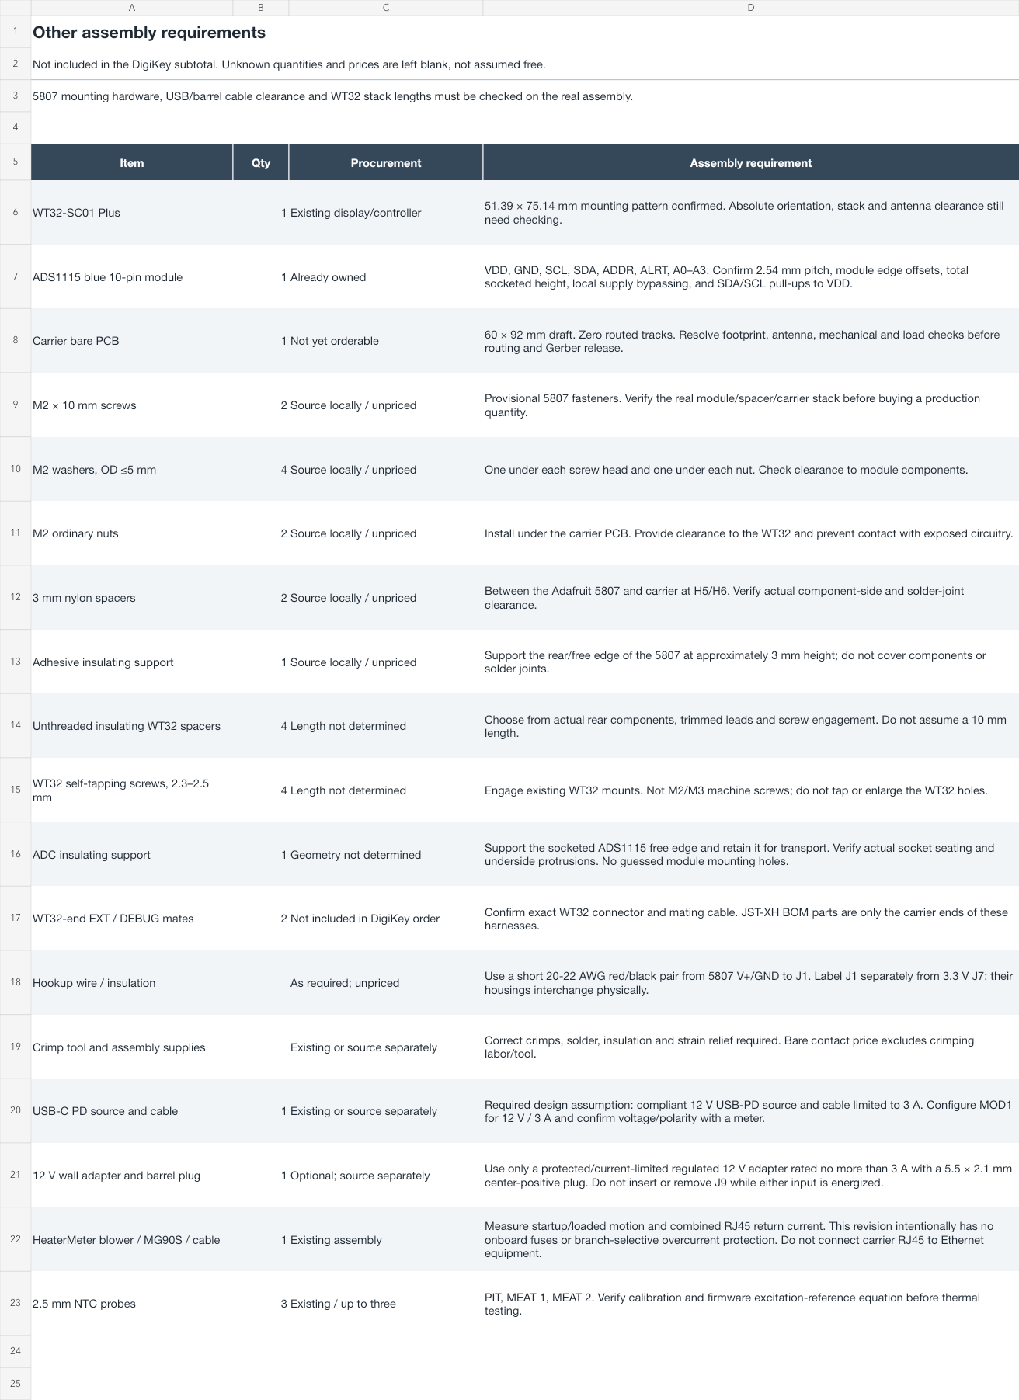
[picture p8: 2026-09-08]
work/bom-build/final-b-t2f0-a5807-s2-other.png

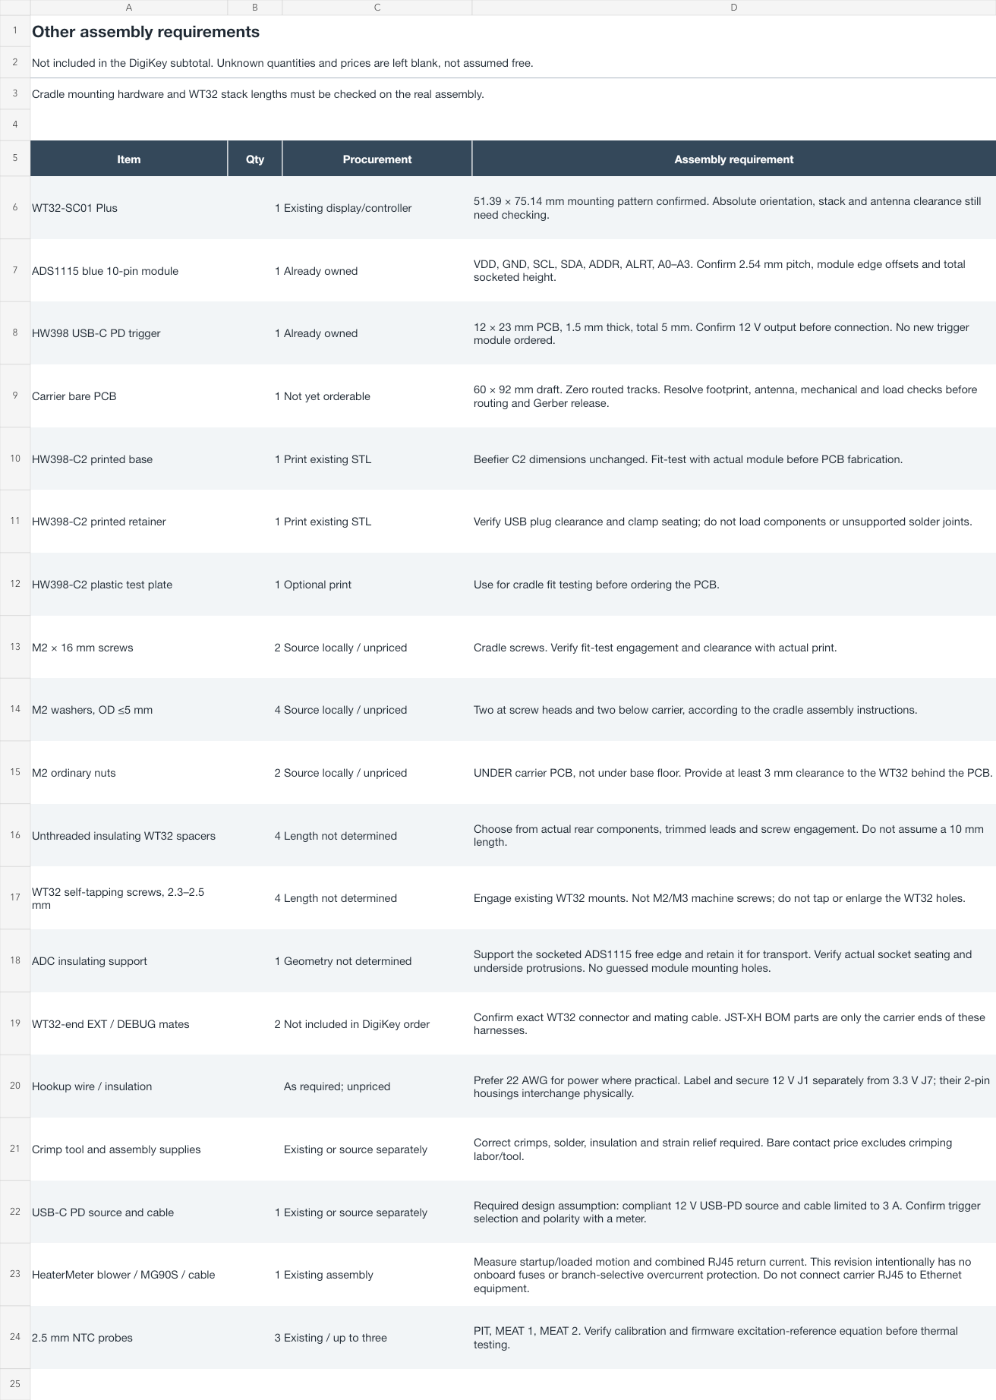
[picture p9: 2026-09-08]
work/bom-build/final-b-t3f0-other.png

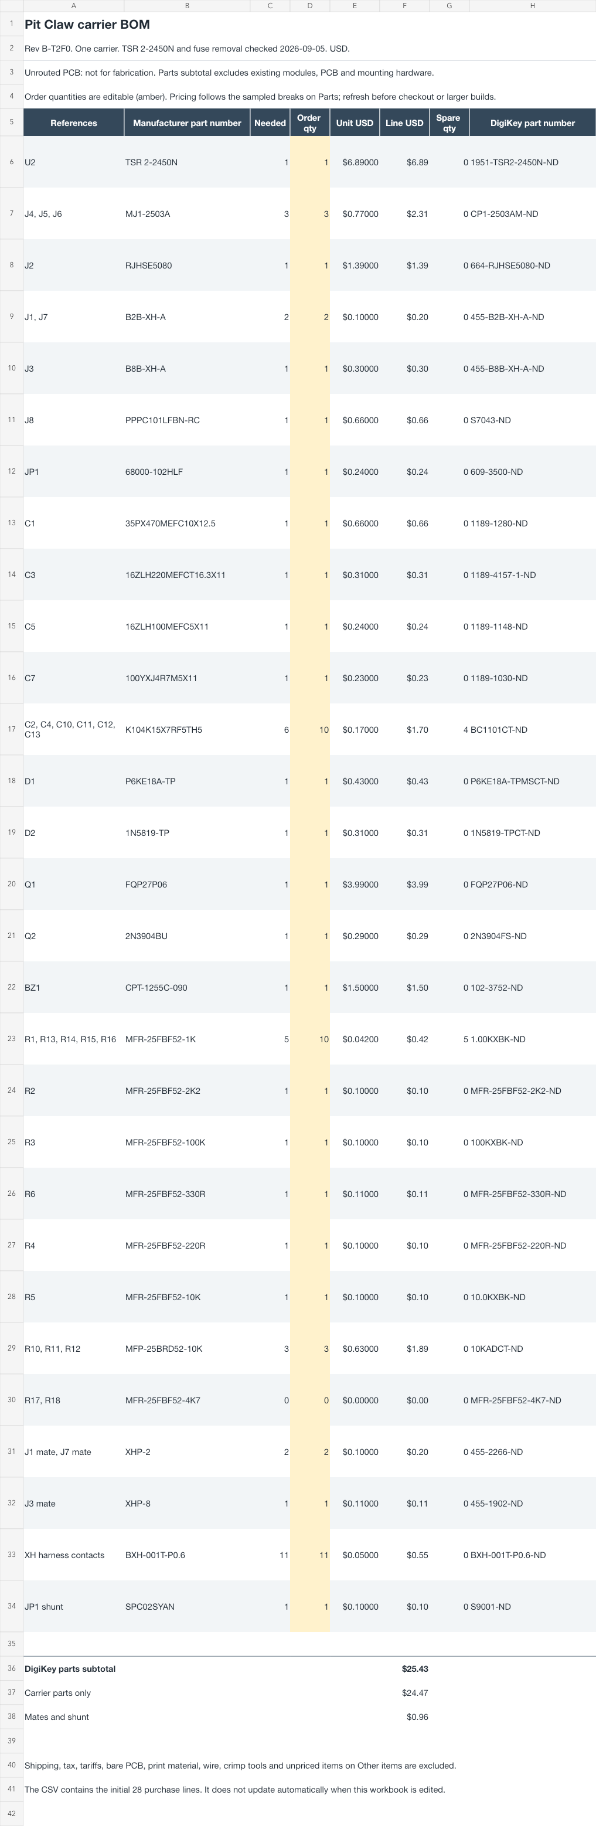
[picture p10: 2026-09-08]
work/bom-build/final-b-t2f0-order.png

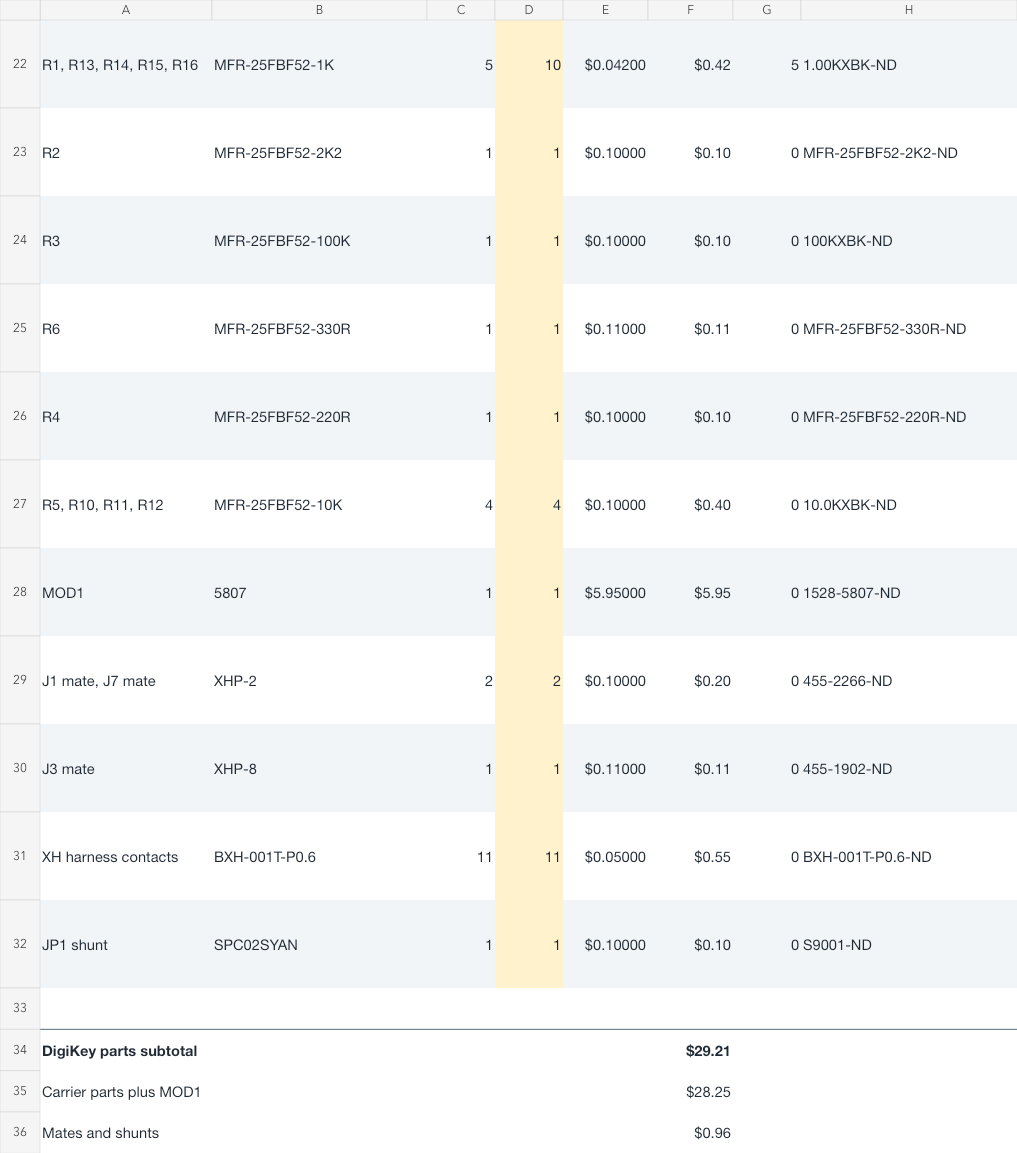
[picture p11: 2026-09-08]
work/bom-build/order-bottom.png

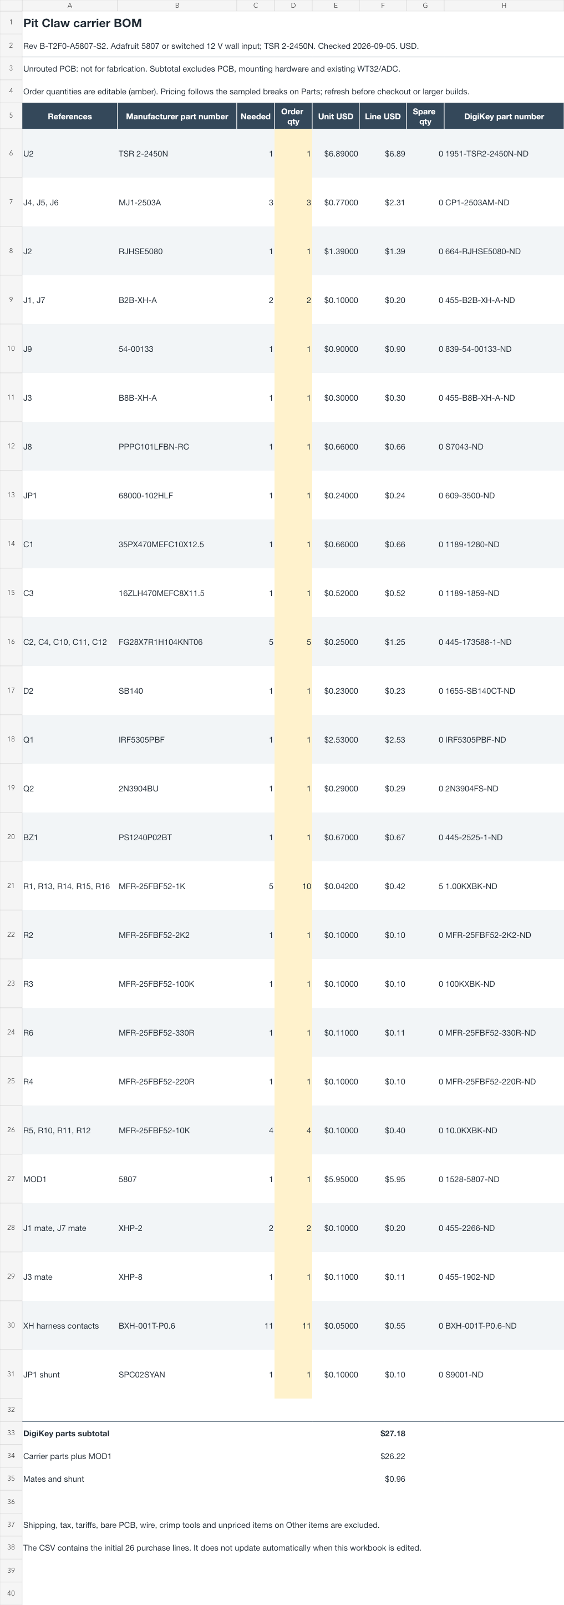
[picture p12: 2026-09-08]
work/bom-build/final-b-t2f0-a5807-s2-order.png

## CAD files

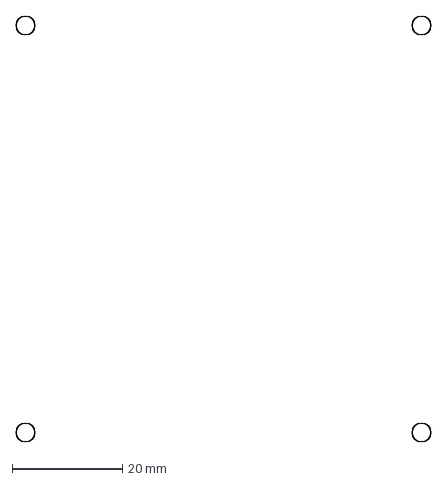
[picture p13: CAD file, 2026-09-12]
enclosure/fusion-r13/mount-pattern.dxf
75.4 x 77.4 mm

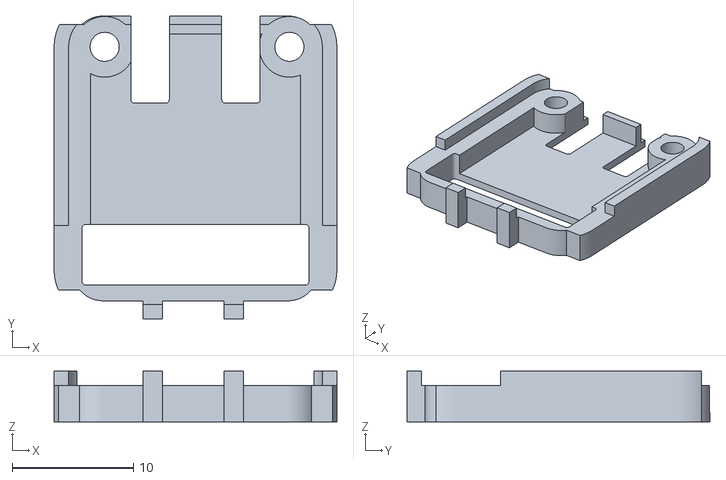
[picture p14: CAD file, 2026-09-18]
enclosure/fusion-r13/native-stl/adafruit5807-base.stl
23.3 x 25.0 x 4.20

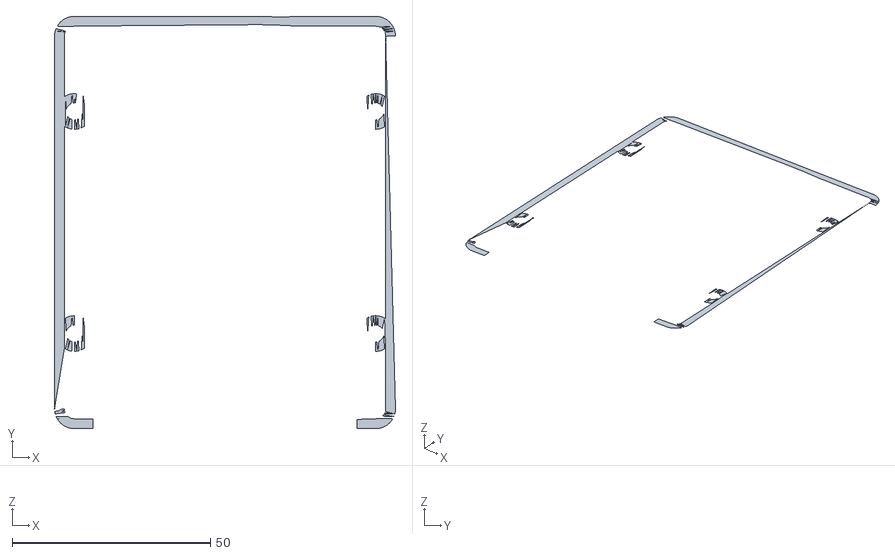
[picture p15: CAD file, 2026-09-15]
enclosure/fusion-r13/reference/logs/nominal-shell-closure-check-intersection.stl
86.0 x 104.0 x 0

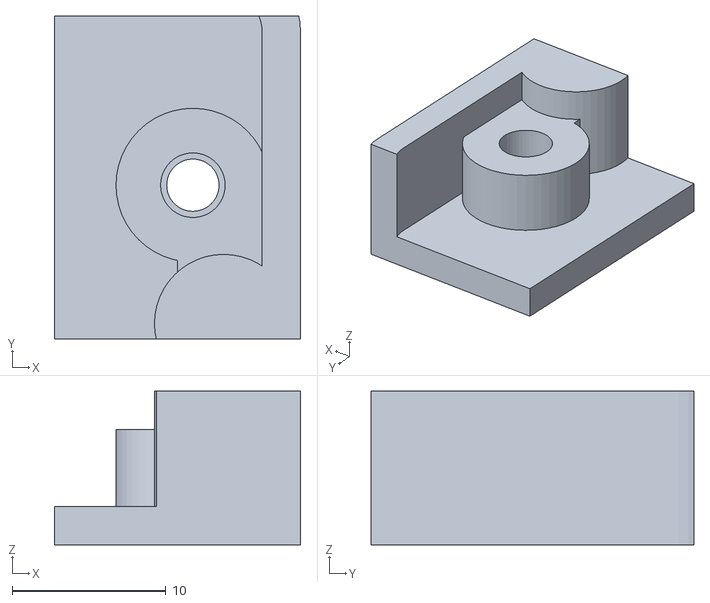
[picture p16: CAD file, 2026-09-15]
enclosure/fusion-r13/stl/mount-coupon.stl
16.0 x 21.0 x 10.0

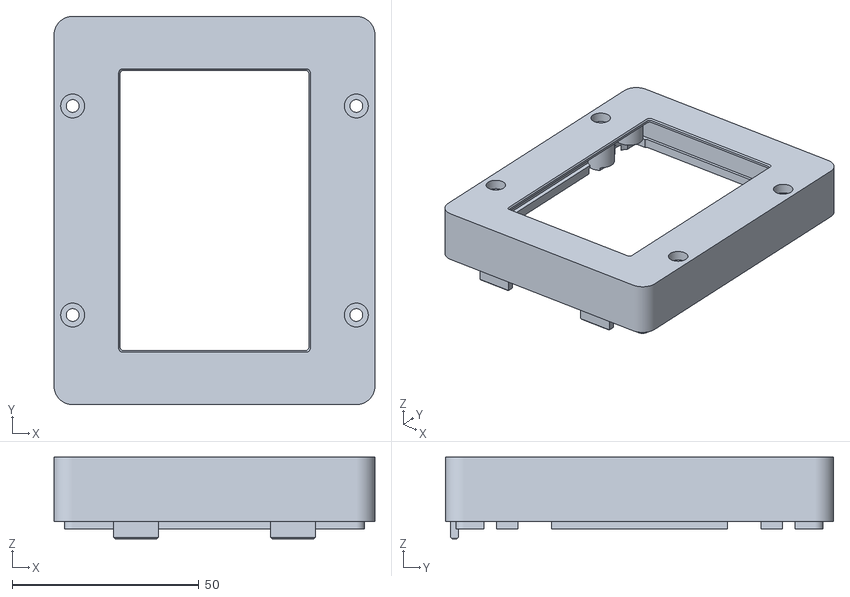
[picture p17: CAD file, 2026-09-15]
enclosure/fusion-r13/native-stl/carrier-top.stl
86.0 x 104.0 x 21.9

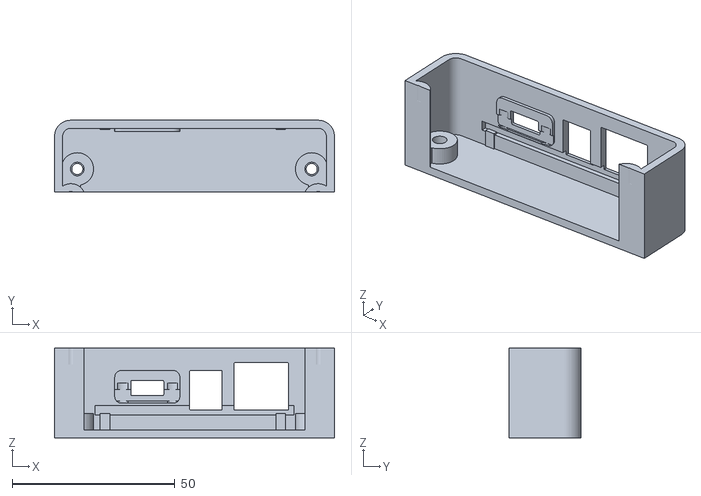
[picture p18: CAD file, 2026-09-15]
enclosure/fusion-r13/reference/fit-coupon.stl
86.0 x 22.0 x 27.6

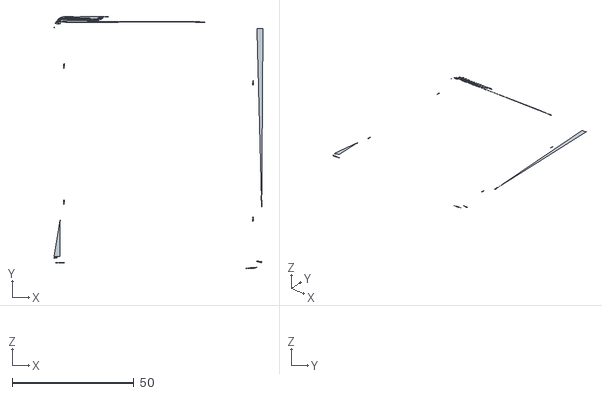
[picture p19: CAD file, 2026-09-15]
enclosure/fusion-r13/reference/logs/nominal-shell-closure-with-fascia-check-intersection.stl
86.0 x 103.7 x 0

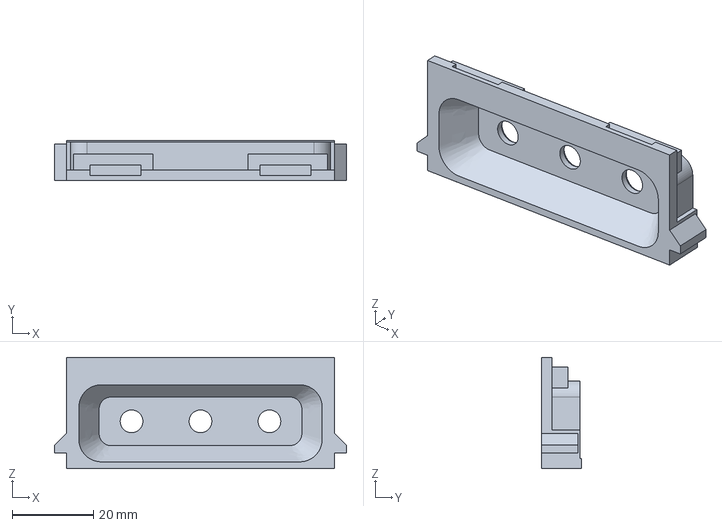
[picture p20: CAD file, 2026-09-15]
enclosure/fusion-r13/step/probe-fascia.step
72.0 x 9.80 x 27.4 mm

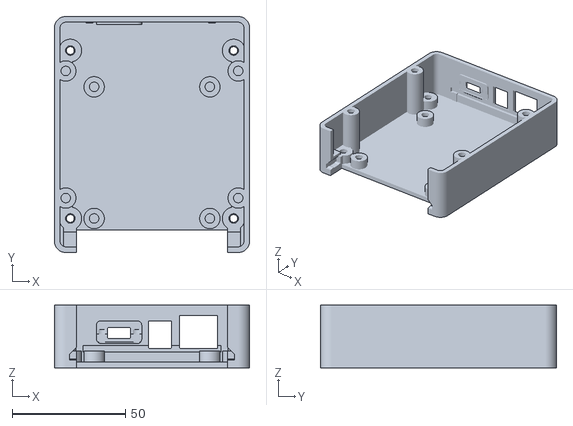
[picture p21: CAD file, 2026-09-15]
enclosure/fusion-r13/native-stl/carrier-bottom.stl
86.0 x 104.0 x 27.6

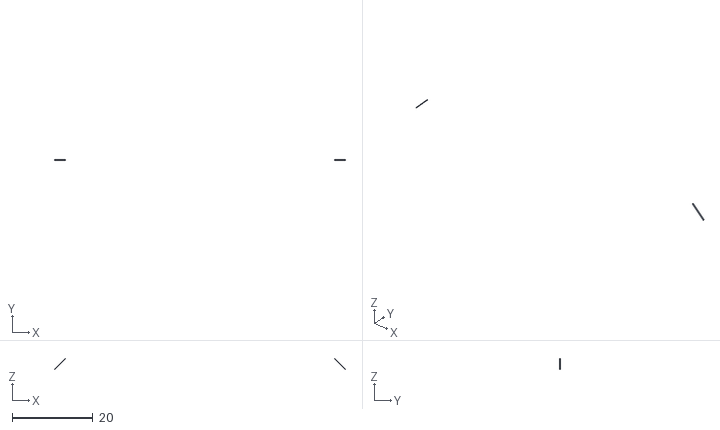
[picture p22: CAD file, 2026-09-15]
enclosure/fusion-r13/reference/logs/guide-capture-early-check-intersection.stl
72.0 x 0.2 x 2.83

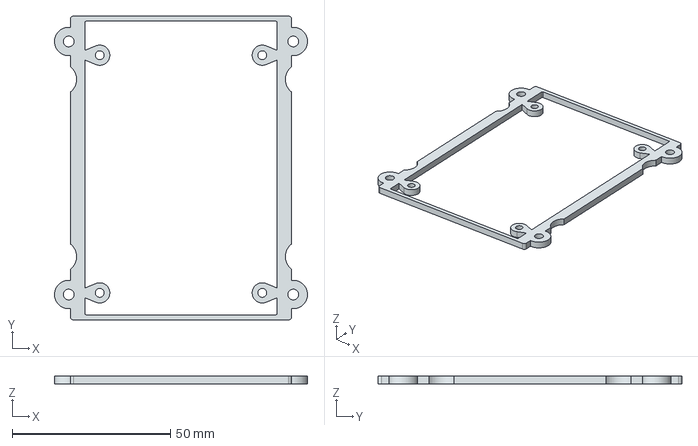
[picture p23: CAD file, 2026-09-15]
enclosure/fusion-r13/step/carrier-retainer.step
80.0 x 96.0 x 2.50 mm

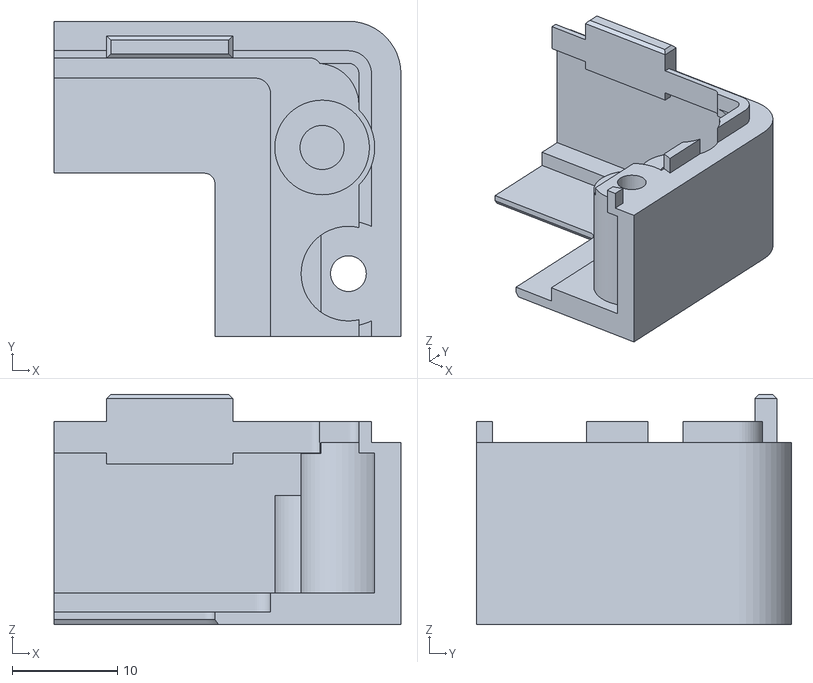
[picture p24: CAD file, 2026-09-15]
enclosure/fusion-r13/stl/joint-coupon-top.stl
33.0 x 30.0 x 21.9

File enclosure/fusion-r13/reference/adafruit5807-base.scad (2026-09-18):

// Adafruit5807 carrier base. Units mm; one printable solid.
// Local print axes: X=10.16-Eagle_u, Y=Eagle_v, Z=height above carrier top.
// The PCB bears at Z3.0 TOTAL, not3.0 plus the0.8mm floor.
// Two M2 clamps resist extraction. Rear stops resist insertion. The curved
// front features are side/corner guides, not positive forward load stops.
// Source: Adafruit-USB-Type-C-Power-Delivery-Dummy-Breakout-PCB Eagle board.
// use <adafruit5807-base.scad> imports ada5807_base() without rendering it.

module ada5807_rounded_2d(x0,x1,y0,y1,r) {
    translate([(x0+x1)/2,(y0+y1)/2])
        offset(r=r) square([x1-x0-2*r,y1-y0-2*r],center=true);
}
module ada5807_board_2d(extra=0) {
    ada5807_rounded_2d(-extra,20.32+extra,-extra,23.495+extra,2.54+extra);
}
module ada5807_band_2d(inner_offset,v0,v1) {
    intersection() {
        difference() {
            ada5807_board_2d(1.5);
            ada5807_board_2d(inner_offset);
        }
        translate([-5,v0]) square([30,v1-v0]);
    }
}
module ada5807_lower_2d() {
    union() {
        ada5807_band_2d(-1.5,.9,22.8);
        intersection() { ada5807_board_2d(); square([20.32,1.1]); }
        for(u=[6.2,12.9]) translate([u,-1.5]) square([1.6,2.6]);
        for(u=[2.413,17.653]) translate([u,20.955]) circle(d=5);
    }
}
module ada5807_upper_2d() {
    union() {
        ada5807_band_2d(.3,6.2,22.8);
        for(u=[6.2,12.9]) translate([u,-1.5]) square([1.6,1.2]);
    }
}
module ada5807_clearances_2d() {
    ada5807_rounded_2d(.8,19.52,1.3,6.3,.3);
    for(ur=[[4.84,7.995],[12.325,15.48]])
        ada5807_rounded_2d(ur[0],ur[1],16.3,24,.3);
    for(u=[2.413,17.653]) translate([u,20.955]) circle(d=2.4);
}
module ada5807_base() {
    $fn=96;
    // Merge each horizontal section in2D before extrusion. Hidden0.02mm
    // overlaps join adjacent levels while preserving all exposed surfaces.
    mirror([1,0,0]) translate([-10.16,0,0]) union() {
        linear_extrude(height=.8) difference() {
            union() { ada5807_board_2d(); ada5807_lower_2d(); }
            ada5807_clearances_2d();
        }
        translate([0,0,.78]) linear_extrude(height=2.22) difference() {
            ada5807_lower_2d(); ada5807_clearances_2d();
        }
        translate([0,0,2.98]) linear_extrude(height=1.22) difference() {
            ada5807_upper_2d(); ada5807_clearances_2d();
        }
    }
}

ada5807_base();

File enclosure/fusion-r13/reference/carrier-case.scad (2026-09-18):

// PitClaw Rev B carrier enclosure r13: bottom, top, removable fascia and internal retainer.
// Units mm. WT32 uses centered PCB coordinates; the carrier is shifted toward
// the power end by carrier_case_offset_y from the generated interface.
// This is a fit prototype, not a mechanically released / weather-rated case.
// WT32 OEM holes are REAR blind bosses: do not screw through the glass / PCB.
// See ../README.md for assembly, dimensions and physical qualification limits.
// All construction stages and the generated interface are included locally.
include <carrier-interface.scad>
use <adafruit5807-base.scad>

// Views also include fit-coupon and insert-coupon for first-print calibration.
// Single-part views are oriented flat on the build plate.
// Diagnostics insertion-check, carrier-installation-check and
// electronics-closure-check must render EMPTY.
part = "assembled";
show_electronics = true;
show_fasteners = true;
$fn = 48;
eps = 0.02;

// Shell and registration. Closure screws sit beyond the free LONG board sides.
case_width = 86;
case_length = 104;
wall = 2.5;
floor_thickness = 2.5;
front_plate = 3;
corner_radius = 5;
case_closure_xy = [[-38,-28],[38,-28],[-38,28],[38,28]];
locating_lip_height = 2;
locating_lip_wall = 1.2;
locating_lip_clearance = 0.3;

// User M3 insert: measured OD4.0..5.0; L4.0 assumed; accepted pilot4.2.
// Print an insertion coupon in the chosen material before committing the case.
insert_od = 5.0; // user-measured maximum knurl diameter
insert_length = 4;
insert_pilot = 4.2; // accepted pilot for user inserts
insert_bore_depth = 5;
insert_boss_od = 9;
carrier_standoff = 5;
minimum_floor_under_insert = 2.5;
m3_clearance = 3.4;
m3_head_clearance = 6.4;
closure_head_recess = 3.2;
// At the default stack, M3x18 closure screws give 3.9 mm insert engagement
// and 1.1 mm bore-bottom clearance. Verify engagement on the actual print.
// Carrier: M3x6 + 0.5 mm washer. Retainer: M3x6 button heads, without washers.

// Conservative vertical stack. Component and cable envelopes require samples.
carrier_component_height = 16;    // provisional; requires Q1 flat on the carrier
                                  // covers mated JST / socketed ADC envelopes
// K1 is modeled separately from the CAD contract at 16.2 mm seated height.
// Its local reserved gap is 2.8 mm; do not pretend it fits the 16 mm envelope.
board_gap = 3;                    // below the lowest display/retainer screw head
wt32_size = [60,92,10.8];          // footprint and nominal rear mounting-boss datum
// The 10.8 mm datum is not a maximum rear-component or mated-connector height.
// Fit-check those parts and the harness within the reserved rear stack below.
wt32_mount_xy = [[4.305,6.52],[55.695,6.52],
                 [4.305,81.66],[55.695,81.66]];
wt32_active = [49.56,74.04];       // manufacturer drawing, centered on front
window_size = [50.6,75.1];        // provisional touch/display edge allowance
glass_recess = 1.5;
front_pad_compressed = 0.3;       // soft perimeter strip on inactive glass border
module_side_clearance = 0.6;      // body tolerance plus print allowance; no glass pinch

// The manufacturer's side view places the rear boss face 10.8 mm behind glass.
// Verify the purchased module, screw type/engagement, and cable exits physically.
// Four small screws pass through retainer INTO the OEM's rear blind bosses.
wt32_rear_mount_depth = 10.8;     // glass front -> OEM boss rear face; sample-verify
retainer_thickness = 2.5;        // retain stiffness along the long, narrow webs
small_screw_head_height = 2;
small_screw_clearance = 2.8;      // provisional; OEM pilot is shown as diameter2.3
small_screw_head_od = 4.8;
retainer_outer = [70,96];
retainer_inner = [60.8,92.8];
retainer_tab_od = 6.4;
retainer_anchor_xy = [[-35.5,-40],[35.5,-40],[-35.5,40],[35.5,40]];
retainer_anchor_od = 9;
retainer_anchor_head_od = 5.7;   // ISO 7380 M3 button head, without washer
retainer_anchor_head_height = 1.65;
retainer_anchor_pilot = insert_pilot; // same M3 heat-set insert as lower shell
retainer_anchor_bore_depth = insert_bore_depth;

// RJ45 and barrel receptacle faces meet the flat exterior wall. USB-C sits
// 2 mm behind it, level with the floor of an access pocket for the cable boot.
// The three independent openings retain solid plastic between the sockets.
carrier_slide_start_y = 0.5;
carrier_slide_lift = 0.3;
power_profile_clearance = 0.5;
carrier_tail_projection = 3;     // maximum clipped lead/solder depth; inspect build
probe_axis_above_pcb = 2.55;      // 5.10 mm housing/bore center; verify sample seating
probe_body_height = 5.1;
probe_plug_opening = 10.5;
rj45_face_size = [15.75,13.21];  // Amphenol RJHSE-5080 housing, W x H above PCB
rj45_body_depth = 14.99;
barrel_face_size = [9,10.8];     // Tensility 54-00133 full housing; parameterized
barrel_body_depth = 14;
barrel_axis_above_pcb = 6.5;     // bore axis, not the housing center
usb_axis_above_pcb = 6.1;         // 3mm spacer + modulePCB + receptacle: measure
usb_face_size = [8.94,3.2];      // shell width from Eagle; height is sample-gated
usb_pocket_size = [20,10];
usb_pocket_depth = 2;
usb_pocket_z_offset = 0.5;       // stronger web above carrier channel; socket stays fixed
usb_inward_backing = 1;
usb_socket_opening = [10.14,4.7]; // fitted shell, thickness/spacer allowance + seat lift
power_face_size = [rj45_face_size,barrel_face_size,usb_face_size];
power_face_center_z = [rj45_face_size[1]/2,barrel_face_size[1]/2,
                       usb_axis_above_pcb];
power_face_corner_r = [0.2,0.2,0.4];

pd_pcb_size = [20.32,23.495,1.6];
pd_spacer_height = 3;
pd_face_overhang = 1.143;
pd_pcb_front_y = carrier_power_face_y[2]-pd_face_overhang;
// Consume the actual H5/H6 coordinates exported from the carrier CAD. These
// holes sit 0.127 mm left of the module center; do not assume +/-7.62.
pd_mount_xy = carrier_pd_mount_xy;
pd_hardware_diameter = 5;        // maximum head/washer/nut envelope, verified BOM
pd_hardware_below_pcb = 3.3;     // nut, washer and screw tip; inspect actual stack
pd_hardware_head_height = 2;    // total upper screw head + washer; inspect stack
blind_pocket_clearance = 0.2;
usb_relief_z_clearance = 0.8;   // separate Z budget; preserve thin blind-pocket Y skins
carrier_channel_xy_clearance = 0.5;
carrier_channel_z_clearance = 0.5;

// Diagnostic witness inputs ONLY; changing these must not resize the printed case.
check_pcb_thickness = 1.6;
check_pd_thickness = 1.6;
check_pd_spacer_height = 3;
check_board_edge_growth = 0;
check_module_shift_x = 0;

// Derived datums: Z=0 is the bottom exterior, +Z points toward the screen.
carrier_bottom_z = floor_thickness + carrier_standoff;
carrier_top_z = carrier_bottom_z + carrier_board_mm[2];
// Retainer and heads reserve 15.3 mm behind the glass with current parameters.
// Actual WT32 rear components and mated connectors still require measurement.
display_rear_depth = max(wt32_size[2], wt32_rear_mount_depth +
                        retainer_thickness + small_screw_head_height);
glass_front_z = carrier_top_z + carrier_component_height + board_gap +
                display_rear_depth;
case_height = glass_front_z + glass_recess;
power_opening_roof_z = max(
    max([for(i=[0:1]) carrier_top_z+power_face_center_z[i]+
        power_face_size[i][1]/2+power_profile_clearance+carrier_slide_lift]),
    carrier_top_z+usb_axis_above_pcb+usb_pocket_size[1]/2);
// Preserve the existing seam and closure grip after fitting the smaller ports.
// At least 2 mm of plastic must remain above every opening.
seam_z = max(carrier_top_z + carrier_component_height + 2,
             carrier_top_z+18.5,power_opening_roof_z + 2);
retainer_top_z = glass_front_z - wt32_rear_mount_depth;
retainer_bottom_z = retainer_top_z - retainer_thickness;
front_pocket_roof_z = glass_front_z + front_pad_compressed;
inside_width = case_width - 2*wall;
inside_length = case_length - 2*wall;
lip_width = inside_width - 2*locating_lip_clearance;
lip_length = inside_length - 2*locating_lip_clearance;
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

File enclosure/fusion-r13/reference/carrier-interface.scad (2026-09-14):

// Generated from carrier CAD by export_enclosure_interface.py. Do not hand-edit.
carrier_board_mm = [60, 92, 1.6];
carrier_mount_xy = [[4.5, 4.5], [55.5, 4.5], [4.5, 62.5], [55.5, 62.5]];
carrier_probe_x = [13.0, 30.0, 47.0];
carrier_power_x = [9.5, 26.5, 44.5];
carrier_power_face_y = [93.5, 93.5, 91.5];
carrier_probe_face_y = -3.0;
carrier_case_offset_y = 4.5;
carrier_underside_pads = [[4.3, 43.0, 2.9456], [9.3, 43.0, 2.2], [43.0, 59.0, 3.2284], [48.0, 59.0, 2.4], [15.0, 38.0, 2.9456], [20.0, 38.0, 2.2], [15.0, 46.0, 2.9456], [20.0, 46.0, 2.2], [15.0, 54.0, 2.9456], [20.0, 54.0, 2.2], [15.0, 65.0, 2.9456], [20.0, 65.0, 2.2], [53.25, 14.5, 2.6627], [56.75, 14.5, 2.0], [30.5, 70.0, 2.9456], [30.5, 75.0, 2.2], [41.5, 45.5, 3.5113], [51.66, 45.5, 2.6], [55.0, 31.0, 3.5113], [55.0, 41.16, 2.6], [54.0, 51.0, 3.0249], [56.5, 51.0, 2.4], [15.85, 88.42, 3.65], [3.15, 88.42, 3.65], [13.06, 85.88, 2.5213], [12.044, 84.1, 1.9], [11.028, 85.88, 1.9], [10.012, 84.1, 1.9], [8.996, 85.88, 1.9], [7.98, 84.1, 1.9], [6.964, 85.88, 1.9], [5.948, 84.1, 1.9], [12.0, 12.0, 2.987], [14.5, 12.0, 2.35], [17.0, 12.0, 2.35], [19.5, 12.0, 2.35], [22.0, 12.0, 2.35], [24.5, 12.0, 2.35], [27.0, 12.0, 2.35], [29.5, 12.0, 2.35], [13.0, 3.5, 1.6], [13.0, 8.1, 2.7707], [11.2, 6.0, 2.5], [14.8, 6.0, 2.5], [30.0, 3.5, 1.6], [30.0, 8.1, 2.7707], [28.2, 6.0, 2.5], [31.8, 6.0, 2.5], [47.0, 3.5, 1.6], [47.0, 8.1, 2.7707], [45.2, 6.0, 2.5], [48.8, 6.0, 2.5], [40.0, 12.0, 3.0249], [42.5, 12.0, 2.4], [13.0, 33.0, 2.9456], [15.54, 33.0, 2.2], [18.08, 33.0, 2.2], [20.62, 33.0, 2.2], [23.16, 33.0, 2.2], [25.7, 33.0, 2.2], [28.24, 33.0, 2.2], [30.78, 33.0, 2.2], [33.32, 33.0, 2.2], [35.86, 33.0, 2.2], [26.5, 79.9, 3.4806], [26.5, 85.8, 2.9], [31.2, 82.7, 2.9], [55.0, 23.5, 2.8042], [55.0, 26.04, 2.1], [30.34, 46.33, 3.6527], [30.34, 56.49, 2.7], [30.34, 64.11, 2.7], [37.96, 61.57, 2.7], [37.96, 46.33, 2.7], [43.3, 41.0, 3.3698], [45.84, 41.0, 2.5], [48.38, 41.0, 2.5], [5.5, 74.0, 2.5213], [8.04, 74.0, 1.9], [10.58, 74.0, 1.9], [3.0, 14.5, 2.0], [3.0, 22.12, 2.0], [15.0, 42.0, 2.0], [22.62, 42.0, 2.0], [15.0, 50.0, 2.0], [22.62, 50.0, 2.0], [15.0, 58.0, 2.0], [22.62, 58.0, 2.0], [26.0, 38.0, 2.0], [33.62, 38.0, 2.0], [26.0, 45.0, 2.0], [26.0, 52.62, 2.0], [26.0, 56.0, 2.0], [26.0, 63.62, 2.0], [26.0, 42.0, 2.0], [33.62, 42.0, 2.0], [7.0, 14.0, 2.0], [7.0, 21.62, 2.0], [3.0, 52.0, 2.0], [10.62, 52.0, 2.0], [3.0, 25.0, 2.0], [3.0, 32.62, 2.0], [3.0, 56.0, 2.0], [10.62, 56.0, 2.0], [7.0, 25.0, 2.0], [7.0, 32.62, 2.0], [17.0, 70.75, 3.2284], [19.54, 70.75, 2.4], [22.08, 70.75, 2.4]];
carrier_relay_box = [29.0, 45.0, 10.3, 20.3, 16.2];
carrier_pd_mount_xy = [[36.753, 87.817], [51.993, 87.817]];
carrier_component_boxes = [[0.64, 36.84, 12.32, 12.32, 16], [40.45, 53.95, 10.1, 10.1, 16], [15.44, 36.64, 4.12, 2.72, 16], [15.44, 44.64, 4.12, 2.72, 16], [15.44, 52.64, 4.12, 2.72, 16], [15.44, 63.64, 4.12, 2.72, 16], [50.95, 10.45, 8.1, 8.1, 16], [29.14, 70.44, 2.72, 4.12, 16], [41.45, 44.1, 10.26, 2.8, 16], [53.6, 30.95, 2.8, 10.26, 16], [51.5, 48.6, 7.5, 5.85, 16], [9.5, 9.6, 22.5, 5.85, 16], [37.5, 9.6, 7.5, 5.85, 16], [10.4, 17.44, 28.12, 17.12, 16], [53.68, 22.18, 2.64, 5.18, 16], [40.445, 18.43, 10.79, 21.58, 6.5], [5.51, 71.47, 5.06, 4.3336, 16], [1.7, 14.45, 2.6, 7.72, 16], [14.95, 40.7, 7.72, 2.6, 16], [14.95, 48.7, 7.72, 2.6, 16], [14.95, 56.7, 7.72, 2.6, 16], [25.95, 36.7, 7.72, 2.6, 16], [24.7, 44.95, 2.6, 7.72, 16], [24.7, 55.95, 2.6, 7.72, 16], [25.95, 40.7, 7.72, 2.6, 16], [5.7, 13.95, 2.6, 7.72, 16], [2.95, 50.7, 7.72, 2.6, 16], [1.7, 24.95, 2.6, 7.72, 16], [2.95, 54.7, 7.72, 2.6, 16], [5.7, 24.95, 2.6, 7.72, 16], [12.04, 68.81, 15.0, 8.6, 16]];
carrier_component_refs = ["BZ1", "C1", "C10", "C11", "C12", "C2", "C3", "C4", "D2", "D3", "J1", "J3", "J7", "J8", "JP1", "Q1", "Q2", "R1", "R10", "R12", "R12", "R13", "R14", "R15", "R16", "R2", "R3", "R4", "R5", "R6", "U2"];

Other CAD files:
enclosure/fusion-r13/reference/adafruit5807-base.stl
enclosure/fusion-r13/step/adafruit5807-base.step
enclosure/fusion-r13/native-stl/probe-fascia.stl
enclosure/fusion-r13/reference/carrier-bottom.stl
enclosure/fusion-r13/native-stl/carrier-retainer.stl
enclosure/fusion-r13/pitclaw-enclosure-r13.f3d
enclosure/fusion-r13/reference/carrier-retainer.stl
enclosure/fusion-r13/reference/carrier-top.stl
enclosure/fusion-r13/reference/insert-coupon.stl
enclosure/fusion-r13/reference/joint-coupon-bottom.stl
enclosure/fusion-r13/reference/joint-coupon-fascia.stl
enclosure/fusion-r13/reference/logs/guide-capture-front-check-intersection.stl
enclosure/fusion-r13/reference/logs/guide-capture-middle-check-intersection.stl
enclosure/fusion-r13/reference/logs/guide-capture-midfront-check-intersection.stl
enclosure/fusion-r13/reference/logs/guide-capture-rear-check-intersection.stl
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

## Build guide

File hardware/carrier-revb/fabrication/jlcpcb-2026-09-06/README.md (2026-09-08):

# JLCPCB bare-board prototype package

**Final review: PASS for a small bare-PCB prototype order, 2026-09-06.**
The final native ERC, DRC, schematic parity and unconnected counts are all zero.
Independent inspection of the exact archive finds no copper opens or shorts
across 31 nets, and all 120 plated holes/slots plus 11 nonplated holes match.
Both Gerber faces were rendered and visually inspected. Physical qualification
and the fabricator's own upload/CAM acceptance remain as described below.

Upload **`pitclaw-carrier-jlcpcb.zip`**. It contains the two copper layers,
two solder-mask layers, two legend layers, one closed board profile and
separate plated/nonplated Excellon drill files. The 12 plated slots are encoded
as G85 slots. The archive is for manual through-hole assembly; it is not a
JLCPCB assembly-service package. Drill maps, previews and review documents are
outside the upload archive.

## Order settings

| Setting | Value |
|---|---|
| Service | Bare PCB, single board; no assembly or stencil |
| Quantity | 5 suggested for the first prototype run |
| Dimensions | 60 × 92 mm |
| Material / layers | FR-4 / 2 copper layers |
| Board thickness | 1.6 mm |
| Outer copper | 1 oz |
| Solder mask / legend | Green / white |
| Surface finish | Lead-free HASL |
| Outline process | Ordinary CNC routing, individual boards |
| Via treatment | Ordinary tented vias; no filling, capping or special plugging |
| Special features | No impedance control, castellations, edge plating or V-scoring |

Green mask, 1 oz and these drill/slot sizes were checked against
[JLCPCB's published capabilities](https://jlcpcb.com/capabilities/pcb-capabilities/)
on 2026-09-06. Standard board tolerances still apply. If the upload viewer
does not detect **2 layers, 60 × 92 mm, 120 plated holes/slots and 11 nonplated
holes**, investigate the discrepancy before checkout. Hole counts include vias;
some viewers display vias and slots separately. Factory CAM acceptance and the
live quote have not been obtained, and no order has been submitted.

## Verification evidence

- [Release manifest](manifest.json): SHA-256 of source PCB, schematic, project
  rules, successful native verification, every CAM file and the final ZIP.
- [Independent CAM audit](review/cam-audit.json): reopens the exact ZIP with
  Gerbonara, checks every drill's plating, diameter, location and slot direction,
  confirms the closed outline and compares Gerber copper connectivity to the
  native pad nets using independent vector geometry.
- [Top Gerber preview](review/gerber-top.svg) and
  [bottom Gerber preview](review/gerber-bottom.svg), with the bottom viewed from
  the solder side. These are rendered from the manufacturing archive.
- [Native checks](../../verification/README.md),
  [DFM review](../../verification/jlc-dfm-review.md),
  [footprint review](../../verification/jlc-footprint-review.md), and
  [enclosure review](../../verification/jlc-mechanical-review.md).

The CAM audit allows only Excellon's 0.001 mm coordinate quantization. Its arc
approximation is at most 0.002 mm. It checks connectivity separately from native
KiCad DRC and does not replace the fabricator's CAM process. Gerbonara reports
KiCad's accepted G90 statement position and the intentionally absent paste
layers; these do not change the parsed geometry.

## Changes made by the order review

- Corrected U2's offset body/courtyard and increased its drills from Ø1.0 to
  Ø1.4 mm, with Ø2.0 mm pads, to fit the tolerated Traco square pins. Moved U2
  0.75 mm toward the probe end to retain connector clearance.
- Enlarged J8 socket drills to Ø1.05 mm, meeting the socket drawing's Ø1.02 mm
  recommendation.
- Extended J9's 0.8 mm-wide plated slots from 1.5 to 1.6 mm to meet JLCPCB's
  minimum 2:1 slot aspect ratio. Pin centers and slot directions are unchanged.
- Increased visible legend height/stroke to 1.0/0.15 mm, cleared overlapping
  labels and enforced manufacturing clearances in the native project rules.
- Moved SERVO_SIG outside the converter body and added two parallel power-size
  ground stitches. The original front wall-power trunk retains a 1.54 mm overlap
  along the maximum converter body edge to preserve the broad ground return;
  this is a documented exception to Traco's generic under-body routing guidance.
  Both ground layers were refilled. The schematic, relay selection and BOM part
  identities are unchanged.

## Prototype limits

This package supports a **small bare-PCB prototype order**, followed by assembly
and fit development. The exact owned ADS1115 module's header offsets and seated
height are not backed by a controlled drawing or physical measurement. Its
fit remains a possible first-board respin risk. The printed enclosure also
needs first-fit work at the tight carrier channel, inserts and USB relief.

Before powered use, verify harness polarity, the 5807's 12 V configuration,
module bypassing/pull-ups, relay transfer and the actual loads. J2's shared
blower/servo return is limited to 1.5 A; U2 supplies at most 2 A on 5 V. Check
blower freewheel current and temperatures in the case. These are assembly/load
qualification steps; no physical testing was performed by this review.

## Re-export after an edit

Run `tools/check_draft.py` with KiCad 9 Python, then `tools/export_jlc.py` with
`--output` set to a new release directory and `--cam-python` pointing to Python
with Gerbonara 1.6.3 and Shapely 2.x. The checker refuses weakened manufacturing rules, and the exporter requires
PCB, schematic and project-rule hashes to match the successful native report. Reconcile footprint and enclosure
reviews after geometry changes; a successful export alone does not repeat
those engineering reviews. Do not substitute an intermediate file from `work/`.

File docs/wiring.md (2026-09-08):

# Rev B-T2F0-A5807-S4 carrier wiring

This net list matches the fuse-free KiCad engineering draft in
[`hardware/carrier-revb`](../hardware/carrier-revb/README.md). The PCB has two-layer routing;
the [JLCPCB package](../hardware/carrier-revb/fabrication/jlcpcb-2026-09-06/README.md)
targets a small bare-board prototype run. Physical fit and load qualification remain.

## External connectors

- J2: HeaterMeter-compatible unmagnetized RJ45/8P8C output. **Not Ethernet.**
- MOD1: Adafruit 5807 USB-C PD power inlet, mounted through H5/H6 and connected
  to J1 with a short 20-22 AWG red/black pair.
- J9: Tensility 54-00133 5.5 × 2.1 mm center-positive 12 V inlet.
- K1: automatic wall-priority changeover relay inside the enclosure; JP2 is removed.
- J4/J5/J6: PCB-mounted 2.5 mm mono probe jacks for PIT, MEAT 1 and MEAT 2.
  They face one short end of the landscape enclosure. The opposite short end
  groups USB-C power, J9 barrel power and the powered J2 fan/servo RJ45.

## Power

```text
Adafruit 5807 V+  -> J1 pin 1 -> PD_12V -> K1 NC
Adafruit 5807 GND -> J1 pin 2 -> GND

Adapter center -> J9 pin 1/A -> WALL_12V -> K1 NO and coil
Adapter sleeve -> J9 pin 2/B -> GND
J9 pin 3/C -> unused (normally closes to pin 2/B, NOT pin 1/A)
K1 COM -> +12V
K1 coil -> raw WALL_12V / GND
D3 across coil: cathode WALL_12V, anode GND
K1 de-energized = USB-PD; energized = wall input

+12V -> U2 pin 1 (VIN)
GND  -> U2 pin 2
U2 pin 3 (5 V) -> +5V

+5V -> JP1 -> +5V_WT32 -> WT32 EXT pin 1
+5V --------------------> RJ45 pin 3 (MG90S supply)
GND ---------------------> WT32 EXT pin 2 and RJ45 pin 4
```

U2 is the fixed-output Traco TSR 2-2450N. Do not fit a Mini100 or adjustable
module in this 3-pin footprint. Configure MOD1 for a 12 V / 3 A request and
meter-check voltage and polarity before connection.

Use a regulated 12 V, 5.5 × 2.1 mm, center-positive wall adapter rated no more
than 3 A. K1 is the G5Q-1 DC12 SPDT relay: its coil is powered directly from
WALL_12V and draws approximately 33.3 mA / 0.4 W. The changeover contact selects
one positive input at a time. With both inputs connected, wall power has priority;
an unpowered barrel plug leaves USB-PD selected. JP2 is removed.

Switchover may briefly interrupt power and restart the controller. D3 suppresses
the coil but slows release. This is wall-presence selection, not a voltage
supervisor: use a regulated adapter and test brownout, contact inrush and restart
behavior with the actual loads. K1 NC is rated 3 A at 30 VDC; NO is 5 A at 30 VDC.
See the [Omron G5Q datasheet](https://omronfs.omron.com/en_US/ecb/products/pdf/en-g5q.pdf).

The S2 wiring used J9's sleeve switch as a positive selector and would short PD
to ground with an empty jack. Use the corrected S4 mapping above.

F1–F4 are absent. Use only protected/current-limited regulated 12 V sources
rated no more than 3 A.
The carrier and output branches do not have independent overcurrent protection.
JP1 is retained only to isolate the WT32's carrier 5 V feed when its USB port is
used; it is not a fuse.

C1/C2 decouple +12V to ground. C3 (470 uF) and C4 decouple +5V to ground. D1,
C5, C7 and C13 are removed. For a 12 V request the 5807/HUSB238 overvoltage
shutdown acts below the former P6KE18A's minimum breakdown; C3 consolidates the
former two 5 V bulk capacitors.

## WT32 EXT

| EXT pin | Net | Carrier connection |
|---:|---|---|
| 1 | +5V_WT32 | From +5V through JP1 |
| 2 | GND | Common ground |
| 3 | GPIO10 | ADS1115 SDA |
| 4 | GPIO11 | ADS1115 SCL |
| 5 | GPIO12 | R2/Q2 blower command |
| 6 | GPIO13 | R4/R5 servo signal |
| 7 | GPIO14 | R6/passive piezo |
| 8 | GPIO21 | Unconnected spare |

## WT32 DEBUG analog supply

| WT32 DEBUG pin | J7 pin | Connection |
|---:|---:|---|
| 2 | 1 | +3V3_A for ADS1115 and probe excitation |
| 7 | 2 | Ground |

No 3.3 V LDO is fitted. Never inject an external supply into J7. Verify the
actual DEBUG orientation and loaded 3.3 V rail; keep motor current out of this
harness. The carrier has no C7/C13 or R17/R18: install the ADC module only after
confirming it has local supply bypassing and SDA/SCL pull-ups to VDD.

## Blower, servo and buzzer

```text
                       Q1 IRF5305PBF P-channel
+12V ---------------- source
+12V -- R1 1k ------- gate
                       drain -----------------> FAN_OUT -> RJ45 pin 5
                         |
                         +---- D2 cathode
                              D2 anode -> GND

GPIO12 -> R2 2.2k -> Q2 base
Q2 emitter -> GND; Q2 collector -> Q1 gate
R3 100k from Q2 base to GND

GPIO13 -> R4 220R -> SERVO_SIG -> RJ45 pin 6
SERVO_SIG -> R5 10k -> GND

GPIO14 -> R6 330R -> BZ1 pin 1
BZ1 pin 2 -> GND
```

GPIO12 high turns the blower on. Firmware starts at 100 Hz power PWM with a
100% kick-start; characterize startup, duty range and heating on the actual fan.
D2 is the inductive flyback path and is not an
overcurrent fuse. Drive BZ1 near 4 kHz and hold GPIO14 low when silent; this
direct drive is only for the selected passive piezo.

## HeaterMeter RJ45 pinout

| Pin | T568B conductor | Function |
|---:|---|---|
| 1 | white/orange | NC |
| 2 | orange | NC |
| 3 | white/green | +5 V MG90S supply |
| 4 | blue | Common blower + servo ground |
| 5 | white/blue | Switched 12 V blower supply |
| 6 | green | Servo PWM |
| 7 | white/brown | NC |
| 8 | brown | NC |

RJ45 pin 4 carries combined blower and servo return current. Confirm numbering
through the actual jack/cable with a continuity meter and validate the shared
contact under worst-case load.

## Probe and ADC channels

Each channel uses a 10 k 1% pull-up to +3V3_A, a 1 k series resistor to the ADC
input and a 100 nF input capacitor to ground. On each MJ1-2503A, pin 1 is sleeve/
ground and pins 2/3 both connect to the probe node. Calibrate all three channels;
the 1% bias part can contribute roughly 0.2–0.5 °C worst-case error across typical
cooking temperatures.

| Jack | Bias | Series/filter | ADS1115 |
|---|---|---|---|
| J4 PIT | R10 | R13/C10 | AIN0 |
| J5 MEAT 1 | R11 | R14/C11 | AIN1 |
| J6 MEAT 2 | R12 | R15/C12 | AIN2 |

R16 connects +3V3_A to AIN3 so firmware can use the measured excitation count:

```text
Rprobe = 10000 * raw_probe / (raw_supply - raw_probe)
open   = raw_probe >= 0.98 * raw_supply
```

Keep the probe/ADC region away from the buck converter and blower current loops
when routing.

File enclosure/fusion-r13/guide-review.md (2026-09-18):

# R13 guide and seam review

R13 promotes the accepted joint-fit geometry to both guides of the full case.
The guide roof and outer-side clearance remain continuous along the 9 mm
engagement. The lower surface deliberately uses relieved travel sections,
ramps and two bearing lands.

| Feature | Accepted geometry |
|---|---|
| Outer-side clearance | 0.30 mm |
| Normal roof clearance | 0.40 mm, equivalent to 0.5657 mm vertically |
| Lower running clearance | 0.30 mm; receiver floor Z3.5 |
| Seating lands | Z3.8 at Y−50…−49.2 and Y−44…−43 |
| Rear stop | Y−43 |
| Minimum receiver roof | Approximately 1.534 mm |
| Fascia side / upper / rear-floor joints | 0.20 mm each; rear-floor gap is along Y |

The male profile is unchanged. On the positive side the receiver outer wall is
X36.3, leaving 2.7 mm of material to X39. Its roof is
`Z=41.8+sqrt(2)*0.4−X`. The opposite guide is mirrored. The floor follows:

```text
(Y,Z): (−52.1,3.5), (−50.6,3.5), (−50,3.8), (−49.2,3.8),
       (−48.6,3.5), (−44.6,3.5), (−44,3.8), (−43,3.8)
```

The early ramp raises a low-running fascia at insertion offsets −7.6…−7 mm,
before the collars enter near −2 mm. The long runner stays over the front land
afterward. The rear land provides a second support about 6.1 mm away, preserving
the original seated height and controlling pitch. The two lands intentionally
contact the runner; they are not lower-clearance regions.

The fascia's upper edge is Z27.4, and key notches extend through Z27.42. Only
the bottom floor strip extends rearward to Y−42.2. The probe plate remains at
Y−44.5…−42.5 and its axes remain Z11.65. The top/bottom seam remains Z27.6.
The lip's outer radius is 2.2; its inner radius stays 1.0.

Sideways and upward offsets are coupled by the sloping guide. Their nominal
clearances are not independent movement allowances. The clamped coupon uses
the actual case screw and tall closure post, rather than relying on hand
pressure alone. Smooth seating must precede screw tightening.

## Verification

The promoted full R13 reference passes **37 geometry and 10 mesh checks**,
including the low-entry slide/rise, both bearing lands and closure with the
fascia. Native checks pass 130 component/case pairs, ten local guide-capture
checks and eight seating-land checks. The allowed +0.1999 mm fascia lift is
clear; larger specified motions meet their retaining surfaces.

The [full native mesh measurements](running-clearance-verification.json)
confirm the accepted gaps at 14 sections across both guides, including ramps
and lands. All four native case meshes pass integrity and sampled comparison
with the reference within 0.03 mm. Their native, reference and print hashes
were checked against [mesh-verification.json](mesh-verification.json).

The unchanged key chamfer leaves 1.6 mm of full-face keeper engagement at the
seated datum, increasing to 1.8 mm at the 0.2 mm upper stop. Its notches remain
open through the raised fascia edge. No added hardware is used for retention.

Reference source SHA-256:
`16b80457079cdaf16f63532c3e2527456ab3959ff25d5feb5606f8637d058153`.
Reference report SHA-256:
`5f6e34e9a3477166d501065919501093bdf4fa44fa284e3e8804bdf05f952442`.
Native archive SHA-256:
`00ab8e3195ccaa0b291149328ca0acde9f45e5b6cc622f8dd61d751e90544316`.

No additional geometry blocker was found. Full physical assembly and printed
durability remain to be checked; intersection volumes are not force ratings.

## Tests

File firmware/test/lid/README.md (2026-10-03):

# Lid-control integration checks

Build the firmware once to fetch its QuickPID and ArduinoJson dependencies, then
run `python test/lid/run_checks.py` from `firmware/`. The runner uses `CXX` (or
`c++`) and creates temporary executables.

- The real embedded `PidController` and QuickPID run against a fake clock/Serial
  boundary. Checks cover cold-start output and integral/derivative reset on
  recovery, resume, timeout and disabling detection. Manual pause tests also cover
  a hot pit with automatic detection Off.
- The tuning fixture holds the measured pit at 210°F against a 225°F target,
  compares the old and new integral gains through the real fan/damper mapping,
  and checks that above-target readings remove heat demand. It measures controller
  response only; actual smoker overshoot and settling require a cook test.
- The settling fixture drives the production controller with below-target
  temperature ripple and compares it with legacy conditional anti-windup. It
  checks accumulated demand, unchanged cold warm-up, 10°F/15°F mode hysteresis,
  overshoot correction, and reset behavior after a fault, target change or pause.
  Cold-start and hot-restart closed-loop checks use an illustrative thermal
  model; their temperature results do not predict this smoker's overshoot.
- The real JSON codec and configuration serializer cover command validation,
  old-config migration, disabled-setting round trips, and complete status packets
  with all eight error slots occupied. These checks do not exercise flash hardware.
  Legacy factory PID settings migrate once without changing damper calibration;
  custom tunings and an explicitly saved rollback survive subsequent loads.

The PlatformIO native PID suite covers settling, threshold boundaries, target
changes, invalid readings, re-arming and clock wraparound. UI tests are in
`test/ui/` and `test/web/test_lid_controls.cjs`.

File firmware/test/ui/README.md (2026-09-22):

# Display interaction and lifecycle checks

These checks create the production widgets on a headless LVGL 480×320 display
with the board's RGB565 format and inject pointer events through LVGL's input
timer. They use a deterministic clock and do not measure ESP32 rendering or
physical touch latency. They are separate from the PlatformIO `native` tests,
which do not link LVGL.

- `test_boot_transition.cpp` checks splash lifetime, startup countdown, reset
  hold timing, and 123 navigation taps covering edges, drift, and rapid changes.
- `test_interactions.cpp` checks committed editor values, independent targets,
  Cancel, one-degree and held adjustments, bounds, Fahrenheit/Celsius conversion,
  condensed history timestamps, axis layout, alarms on all main screens and over
  editors, Settings scrolling, and setup navigation/test feedback. It also checks
  the single Open/Close lid toggle and automatic detection setting, including
  100 pointer taps across the dashboard lid toggle and timeout adjustment buttons,
  Settings scrolling and higher-priority alarm overlap, and
  raised degree symbols through changing digit widths, negative/zero Celsius
  readings, disconnection/reconnection, and compact alarm layouts.
  The physical touch-test screen is checked with five injected positions (including
  a deliberate offset), retained markers/readouts, close/reopen, and timeout with
  a held finger. The diagnostic is invoked directly in these tests; no Touch test entry appears
  in normal Settings. Actual panel alignment still requires touching the hardware.
  Calibration checks cover the measured Y correction, input beyond the original
  screen height, Cancel/timeout rollback, failed Save, successful Save, Reset,
  and bottom navigation with corrected input. Config round trips and invalid
  calibration rejection run with `test/lid/run_checks.py`.
  Damper setup checks cover entry without movement, immediate saved-position tests,
  fallback to saved positions for incomplete/invalid edits, marking both endpoints,
  reversed travel, the three test positions, Stop signal, save failure, Save,
  Cancel, and a timeout that keeps setup open. The host controller checks also
  verify calibrated fault-close and suppression of blower/PID output in setup.

Build the simulator to obtain the matching LVGL library, then run both checks:

```sh
CPATH=/opt/homebrew/include pio run -e simulator
python3 test/ui/run_checks.py
```

The runner defaults to Homebrew SDL on macOS and `/usr` elsewhere. Supply
`--sdl-prefix /path/to/prefix` for another SDL installation. It compiles checks in
a temporary directory and removes the executables after running them.

To also capture the actual production screens as PNGs:

```sh
python3 test/ui/run_checks.py --capture-dir .pio/ui-screens
```

The capture process uses LVGL rendering and Python's standard library; it needs
no browser or image packages. Generated captures stay in the ignored `.pio/`
directory. The project's main README includes a current dashboard render;
temporary UI reviews and comparisons are not retained in `work/`.

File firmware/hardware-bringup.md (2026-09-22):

# Carrier firmware bring-up

Temperature processing now matches the carrier's 10 k pull-up / NTC-to-ground
divider and uses ADS1115 AIN3 as the measured excitation reference. The accepted
reference range is 3.0–3.6 V; invalid excitation makes every sampled probe
unavailable. Open detection starts at 98% of excitation, short detection at
100 ADC counts, and each failure resets smoothing before recovery.

During normal control, an invalid pit reading immediately stops the blower and
closes the damper in every fan mode, including during kick-start or manual duty.
The PID command is cleared once per fault; outputs stay closed after reconnection
until the next valid scheduled PID calculation.

Blower defaults are provisionally 100 Hz power PWM with 100% startup for 500 ms.
Bench-test the actual two-wire blower for startup, minimum usable duty, current,
gate/output waveforms and MOSFET temperature before cooking.

## Display and touch backend

The original SPI/TFT_eSPI placeholders could not drive this board and overlapped
the carrier servo/buzzer pins GPIO13/14. They have been replaced with the vendor's
PanelLan `BOARD_SC01_PLUS` configuration and LovyanGFX in
[ui_init.cpp](src/display/ui_init.cpp). This configures the parallel display,
backlight on GPIO45, and capacitive touch on I2C controller 1. The carrier ADS1115
continues to use Arduino `Wire` (controller 0) on GPIO10/11.

LCD and touch share GPIO4 reset; firmware pulses it once before driver startup.
The LVGL display explicitly uses RGB565 with 16-bit draw buffers and synchronous
flush completion. LVGL uses the system allocator rather than a fixed 64 KB pool.
The memory configuration is `qio_qspi` for the board's 2 MB QSPI PSRAM; the previous
`qio_opi` setting selected the wrong PSRAM interface.

The manufacturer specifies an ST7796UI display with an 8-bit i8080 bus and an
FT6336U I2C touch controller. The board pin map is:

| Signal | GPIO |
|---|---|
| LCD D0–D7 | 9, 46, 3, 8, 18, 17, 16, 15 |
| LCD write / command-data | 47 / 0 |
| LCD and touch shared reset | 4 |
| Backlight, active high | 45 |
| Touch SDA / SCL / interrupt | 6 / 5 / 7 |

Source: [Wireless-Tag WT32-SC01 Plus datasheet, LCD/touch tables](https://www.tme.eu/Document/e40e2e0db8f76604c11099fc1b945dc2/WT32-SC01.pdf).

Driver reference: [vendor SC01 Plus configuration](https://github.com/smartpanle/PanelLan_esp32_arduino/blob/2bc0d086c9a55f5288d85da6c16968c22744fe5f/src/board/sc01_plus/sc01_plus.cpp).
PanelLan is pinned to that commit; LovyanGFX is pinned to 1.2.28.

The user confirmed the setup wizard is visible and touch works on the USB-only
board. Physical validation still needs to cover the full touch area, colors,
setup completion, and operation with the carrier attached.

## USB-only startup and PWM

An absent ADS1115 produces one diagnostic and leaves probes unavailable; firmware
does not keep polling an ADC that failed initialization. Connect the carrier and
reset to initialize the ADC before testing probes.

At 100 Hz, the S3's 40 MHz LEDC clock cannot generate the original 8-bit PWM
configuration. The hardware now uses 10 bits, with the existing 0–255 public duty
values scaled to 0–1023. Failed initialization leaves the blower pin low. Timer
assignments also prevent buzzer or backlight activity from changing fan PWM:

| Function | LEDC resource |
|---|---|
| Fan | Channel 0, timer 0, 100 Hz / 10 bits |
| Servo | LEDC channel 2 / timer 1, fixed 50 Hz with 14-bit pulse resolution |
| Buzzer | Channel 4, timer 2 |
| PanelLan backlight | Channel 7, timer 3 |

With no stored Wi-Fi network, firmware opens `BBQ-Setup` immediately instead of
making three failing `WiFi.begin()` calls (`0x300a`, invalid SSID). The portal
remains available until configured. The dashboard HTTP listener pauses while the
portal owns port 80, then resumes when provisioning completes. Provisioning is
serviced during the splash and setup wizard as well as normal operation.
WiFiManager normally destroys its portal inside `process()` after saving the
network; the handoff checks whether the portal is still active before stopping
it, avoiding a null-server crash from double shutdown.

Wi-Fi credentials are saved independently of wizard completion. A reboot during
setup can therefore reconnect to the saved network while the wizard is still
unfinished. The wizard now uses live Wi-Fi state: an active setup AP shows the
`BBQ-Setup` join QR, password `bbqsetup`, and portal address; a connected board
shows its current network and a dashboard URL QR instead. While reconnecting,
the join QR is hidden. QR codes use black modules on white with a quiet zone.

## Wizard verification, 2026-09-08

- The user confirmed the phone opens the dashboard at `192.168.0.29` on the home
  network. The stale setup QR was directing the phone to a hotspot that had
  already stopped after Wi-Fi provisioning.
- Firmware build passes: 147,632 bytes static RAM and 1,687,501 bytes flash.
- Simulator build passes with `CPATH=/opt/homebrew/include` to supply the local
  SDL headers. Headless rendering of the actual wizard checks AP-to-connected
  transitions, hidden QR while reconnecting, and layout with a 32-character SSID.
- Apple's Vision QR decoder reads the rendered setup code as
  `WIFI:T:WPA;S:BBQ-Setup;P:bbqsetup;;` and the connected code as
  `http://192.168.0.29`.
- Uploaded only the application partition at `0x10000`; the flash hash verified.
  Saved Wi-Fi and filesystem settings were preserved. The board reconnected at
  `192.168.0.29`, and both the dashboard and `/api/version` returned HTTP 200.
  Setup was already marked complete, so this reboot entered normal operation;
  the corrected wizard states were validated with the renderer above.

## Splash transition freeze, 2026-09-08

After setup was completed, reboot could stop on the splash even though the serial
log reported normal operation. HTTP remained responsive because it runs in an
asynchronous task. A WebSocket client received its initial snapshot but no
periodic messages, confirming that the main loop had stopped.

Splash cleanup deletes the active LVGL screen. The dashboard fade deferred
activation until an animation tick, allowing a refresh with a null active screen.
LVGL's default assertion handler then halted the main loop. `ui_switch_screen`
now loads immediately when no screen is active; ordinary navigation still fades.

The [headless display regression](test/ui/README.md) failed its active-screen
assertion before the fix and passes afterward, including rendered frames and
subsequent settings/dashboard navigation. The production build passes with
147,632 bytes static RAM and 1,687,581 bytes flash, including the payload fix below.

Once the main loop resumed, testing found corrupted error strings in initial
WebSocket snapshots. `buildDataPayload()` retained pointers into a local error
vector that was destroyed before serialization. The payload now owns copies of
the error text. This matters on the USB-only board because all three probes are
reported disconnected during normal operation.

The user confirmed that the uploaded splash fix displays the dashboard and that
the Settings and Graph tabs respond to touch.

The final app-only upload passed flash hash verification and preserved Wi-Fi and
filesystem settings. The dashboard and `/api/version` return HTTP 200. Three
fresh WebSocket connections each received five valid snapshots/periodic updates
with advancing timestamps, correct probe-disconnected messages, and zero fan and
damper output. This verifies main-loop progress beyond the asynchronous HTTP
response. Logs: `/private/tmp/pitclaw-boot-fix-startup.log` and
`/private/tmp/pitclaw-live-updates-check.log`.

## Verification, 2026-09-07

- `pio run -e wt32_sc01_plus`: build and link pass; 147,488 bytes static RAM,
  1,686,481 bytes flash with the corrected display, portal handling and filesystem checks.
- `pio test -e native`: 132 cases pass across nine suites. Five new cases compile
  the actual fan/buzzer hardware branches against a fake Arduino boundary to check
  S3 divider feasibility, duty scaling, kick-start timing, failed initialization,
  and buzzer timer separation.
- Three Wi-Fi tests exercise the actual manager against fake network/portal
  boundaries: first boot without an SSID, automatic portal shutdown after
  provisioning, and explicit shutdown when the portal remains active.
- Uploaded over USB to the ESP32-S3. Startup reports 2,095,103 bytes of PSRAM,
  480x320 RGB565 display initialization, and 100 Hz / 10-bit fan PWM without the
  previous LEDC error. First boot starts the setup AP without the invalid-SSID
  error, then reaches the touchscreen setup wizard.
- Reboot with the saved Wi-Fi network connects successfully; `/api/version`
  responds with HTTP 200 on the device at `192.168.0.29`.
- Final firmware and preserved filesystem image were flashed and their write
  hashes verified. The dashboard root and all six assets return HTTP 200 and
  match the local files byte for byte; `/HNAP1/` returns HTTP 404. The final
  startup capture has no runtime error or panic messages, with one expected
  absent-ADS1115 diagnostic. Log: `/private/tmp/pitclaw-final-startup.log`.

## Development release checks

`ENABLE_RELEASE_UPDATES=0` in `platformio.ini` disables the browser's automatic
and manual GitHub release checks. Set it to `1` to opt in with a stable `x.y.z`
firmware version. Development/prerelease version strings and the simulator skip
release checks. Manual firmware uploads at `/update` remain available on hardware.
The `/api/version` response exposes `releaseUpdatesEnabled` to the web UI.

Verify the browser gate with `node test/web/test_release_updates.cjs`.
Deploy both the firmware and web assets for this setting to take effect.

## Web files and filesystem preservation

Current builds embed `data/` in firmware; ordinary firmware OTA now updates both
interfaces without a filesystem upload. The following notes describe earlier
filesystem-based deployments.

The earlier firmware upload did not include `data/`. The initial board had only
`config.json` in LittleFS, so dashboard requests produced missing-file diagnostics.
Missing cook-session files on first boot and missing HTTP paths now use `stat()`
against the configured mount path; Arduino-ESP32 2.0.14's `LittleFS.exists()` itself
logs an error for absent files. Static serving checks for real files before
handling a request and prefers the uncompressed assets in `data/`.

Before adding web files, the existing LittleFS partition was backed up from
`0xc90000`, size `0x360000`, to `/private/tmp/pitclaw-littlefs-before.bin`.
The backup was unpacked, `data/` was merged, and the resulting image was unpacked
again to compare every file. Existing `config.json` was preserved byte for byte.
The image is `/private/tmp/pitclaw-littlefs-with-web.bin`; verification hashes are
in `/private/tmp/pitclaw-filesystem-manifest.json`. Wi-Fi credentials in NVS are
outside the filesystem partition and are not overwritten.

The installed mklittlefs 2.3 utility cannot unpack the board's LittleFS 2.1 disk
format. For this migration, a local build of upstream `earlephilhower/mklittlefs`
with LittleFS 2.11.1 was used; the globally installed PlatformIO tools were unchanged.
Ordinary `pio run -e wt32_sc01_plus -t uploadfs` replaces the filesystem, so back
up settings and session data first if they need to be retained.

## Verification, 2026-09-05

- `pio test -e native`: all 120 existing cases pass, including eight tests of the actual
  `TempManager::processSample()` path rather than duplicated conversion formulas.
- The additional four `test_control_outputs` cases pass against the production
  output helper, fan controller and servo controller; the 20 PID cases also pass
  after adding the fault interlock (124 native cases total).
- `pio run -e wt32_sc01_plus`: compiles and links with the locally installed
  Espressif32 6.6.0 / Arduino 2.0.14 / TFT_eSPI 2.5.43 dependencies. Build success
  does not validate display pin assignments or touch support.
- No board was connected: ADC fixture tests, blower waveforms/temperature and
  display/touch operation remain unmeasured. The embedded ADC open test now
  requires PIT to be unplugged and actually asserts a rail-relative reading.

Both commands used an isolated writable `PLATFORMIO_CORE_DIR`; no firmware was
flashed. Repeat hardware validation on the actual assembled carrier.

## Reverse-proxy UI deployment, 2026-09-08

Flashed the current firmware and all six web assets to the WT32-SC01 Plus.
A fresh LittleFS backup was merged with `data/` and verified by unpacking the
new image. The saved `config.json` remained byte-for-byte identical, including
when read back from the running controller. Backup, image, and flash logs are
in `/private/tmp/pitclaw-proxy-deploy/`.

Firmware and filesystem flash hashes passed, and serial output confirmed normal
startup at `192.168.0.29`. All six served assets match the source files; GitHub
checks remain disabled and the manual `/update` page responds successfully.
The firmware build and both web regression checks passed. A temporary local
Nginx instance verified the deployed assets, API, and continuing WebSocket
readings under different prefixes over HTTP and HTTPS. The user's Nginx server
still needs the [proxy configuration](docs/reverse-proxy.md).

Mobile header follow-up: deployed a CSS fix that reserves space for the logo
and puts cook times below the logo/buttons on narrow screens, with cache version
`v4`. The previous filesystem image matched the device's full partition digest
before merging the change. Saved configuration, flash hash, normal startup, and
all six served assets were verified. Images and logs are in
`/private/tmp/pitclaw-mobile-header/`. Phone visual verification was unavailable
because no browser was connected.

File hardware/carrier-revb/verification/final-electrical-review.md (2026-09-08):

# Final electrical review — retained relay circuit

Reviewed 2026-09-06. K1 remains G5Q-1 DC12: USB-PD on NC, wall power on NO.
The user's no-fuse prototype choice is preserved. The fabrication review preserves the
schematic connections while correcting footprints and local routing.

**No confirmed schematic pin, polarity or source-selection error was found.**
The completed routing passes native ERC, DRC, connectivity and schematic parity.
The independent return-path review found a narrow J2 ground connection; that
connection was widened and the final saved copper was checked again. Physical
load and assembly qualification remains.

The review read the native schematic, exported KiCad netlist, component
selection and custom footprint definitions. It did not use the generator's
expected-pin-net file as proof of circuit correctness. The inspected netlist
contains 37 electrical components and 104 pin records, including intentionally
unconnected pins. Its normalized `(reference, pin, net)` SHA-256 is
`80ddba3ff031a202070c9084cdbf1d001501f4fd21a33c752aad2997ba2095a9`.

## Confirmed circuit behavior

| Block | Independent finding |
|---|---|
| Source selection | K1 pins 1/5 are the coil; 2 is COM, 3 NO and 4 NC. Native connections put pin 1 and NO on raw WALL_12V, pin 5 on GND, COM on +12V and NC on PD_12V. USB supplies the load with the coil off; wall supplies it with the coil on. |
| Barrel and flyback | J9 center/A is WALL_12V, sleeve/B is GND and switched sleeve/C is unused. D3's cathode is WALL_12V and anode is GND, opposing normal coil voltage. |
| Blower | Q1 is wired 1 gate, 2 drain/FAN_OUT, 3 source/+12V. Q2 is wired emitter to ground, base through R2, collector to Q1 gate. R1 pulls the gate to source; R3 pulls the base down. High GPIO12 turns the blower on; undriven GPIO leaves it off. D2 cathode FAN_OUT/anode GND is the correct high-side freewheel orientation. |
| Power and programming | C1/C3 positive terminals face their respective +12V/+5V rails. U2's native map is 1 VIN, 2 GND, 3 VOUT. JP1 separates carrier +5V from WT32 +5V; remove it before powering WT32 through programming USB. |
| Analog and GPIO | Probe sleeve is ground and both tip pins join the biased probe node. Each ADC channel has its own 1 kΩ/100 nF filter. AIN3 measures excitation; ADDR is grounded for 0x48. Firmware uses ±4.096 V gain, compatible with measuring the 3.3 V rail. EXT GPIO10/11/12/13/14 assignments agree with the WT32-SC01 Plus manual. |

Primary checks: [Omron G5Q](https://components.omron.com/eu-en/system/files/2026-04/datasheet_pdf/J155-E1.pdf),
[Tensility 54-00133](https://tensility.s3.us-west-2.amazonaws.com/imports/product_spec_sheets/54-00133.pdf),
[Infineon IRF5305](https://www.infineon.com/part/IRF5305),
[onsemi 2N3904](https://www.onsemi.com/pdf/datasheet/2n3903-d.pdf),
[Same Sky MJ1-2503A](https://www.sameskydevices.com/product/resource/mj1-2503a.pdf),
[TI ADS1115](https://www.ti.com/lit/ds/symlink/ads1115.pdf), and the manufacturer's
[WT32-SC01 Plus V1.3 manual](https://github.com/janick/WT32-SqLn/blob/main/docs/WT32-SC01-Plus-V1.3-EN.pdf)
already available locally. The subsequent JLCPCB footprint review retrieved
[Traco's manufacturer datasheet through Mouser](https://www.mouser.com/datasheet/3/1230/1/tsr2n_datasheet.pdf)
and confirmed the pin map, 5 V / 2 A rating, 6.5–36 V input range and 820 µF
maximum capacitive load. That drawing also exposed the U2 drill/body defects
corrected for the fabrication package; see [the footprint review](jlc-footprint-review.md).

## Final routed evidence

The checked PCB SHA-256 is
`7d648c85aaa1fabd4f39074680c3daeb83a75353a57960b03cd88eaad8274764`.
The schematic redraw preserves the 104-record pin-map hash above. The current
native checks report **0 ERC violations, 0 DRC violations, 0 unconnected items
and 0 schematic-parity differences**. All 37 electrical references agree with
the BOM and footprints. Eighteen actual jack/contact/source combinations keep
the two positive inputs isolated; this is a topology check, not a relay timing
or fault-current test.

The board contains **314 track segments and 16 vias**, with 1,589.925 mm total
track length. The measured power routing is:

| Net | Routed width and total length at that width |
|---|---|
| PD_12V | 2 mm: 21.580 mm |
| WALL_12V | 2 mm: 80.020 mm |
| +12V | 2 mm: 57.699 mm; 0.3 mm R1 bias branch: 62.071 mm |
| FAN_OUT | 1.2 mm: 81.637 mm |
| +5V | 1.2 mm: 153.167 mm |
| +5V_WT32 | 1.2 mm: 50.461 mm |

The 0.3 mm +12V branch supplies R1's gate bias, approximately 12 mA with the
blower enabled; it does not carry blower or converter load current. C2/C4 were
moved toward U2. The gate-drive components remain spread across the board, so
switching behavior and analog noise still need the intended-load bench test.

Saved GND fills cover 3,070.265 mm² on F.Cu (three regions) and 2,848.010 mm²
on B.Cu (four regions). Counting zones or airwires alone would have missed the
J2 return problem: its original B.Cu throat was approximately 0.6–0.7 mm wide,
and its F.Cu pad region was isolated. The fix moved the nearby servo signal and
added a 1.2 mm GND route from J2 pin 4 toward J9 ground. Its four segments total
20.418 mm and merge into the ground fill.

The order review corrected U2's offset body and enlarged its drills, then moved
its pin row to Y70.75 mm. The servo signal now detours outside the maximum
converter body using two additional signal vias. Two parallel Ø1.2/0.6 mm
GND stitches at (18,78.5) and (20,78.5) mm retain the broad return connection.
The original 2 mm front WALL_12V trunk remains. Its copper occupies a 1.54 mm
strip along the right edge of U2's maximum body envelope. This deliberately
retains the stronger ground return, and does not fully follow Traco's generic
avoid-under-converter trace guidance. Direct converter pin fanouts also remain;
bench noise/thermal testing is still required.

The checker retains an independent geometric test: union actual saved GND
fills, GND tracks and pad/via copper on each layer, then erode the polygons by
half the tested corridor width. A 0.01 mm width allowance avoids collapsing an
exactly nominal-width track to a zero-area line; a pad may meet a surviving
region within the erosion distance plus 0.05 mm. Power-section plated pads
and actual GND vias can join the layer graphs. ADC/DEBUG pads are excluded as
power-return layer bridges. Native KiCad geometry and a separate Shapely
inspection agreed on the original bottleneck; native geometry verifies the
final correction.

On the final board, **J1/J9/U2/C1/C3/D2 and J2 remain connected at the 2 mm
corridor check**, including necessary transitions between layers. The checker
requires 2 mm for the main power landings and at least 1.2 mm for J2's return.
This measures continuity through broad copper regions with short pad-entry
allowances. It does not certify PTH/via resistance, copper thickness, current
sharing, voltage drop, temperature or immunity to blower noise.

Four top mounting-washer keepouts also pass: tracks, vias, pads and pours are
excluded over Ø7.4 mm. Circular NPTH exemptions stay within 1.7 mm radius on
both top-washer and underside-boss rules. This fixes the previously exposed
corners of square exemptions while preserving the actual 3.2 mm mounting holes.

Reproducible measurements and per-net narrow sections are retained in
[summary.json](summary.json); the native reports and checker results are in
[README.md](README.md). The checker requires a routed board and zero native
unconnected items; it no longer accepts the old unrouted draft state.

## Physical load and assembly checks that remain

1. **J2 is rated 1.5 A per contact.** Pin 4 carries the combined blower and
   servo return. Validate their simultaneous current, startup waveform, cable
   voltage drop and contact heating against that rating; a 3 A input source
   does not establish compliance. This is a load-acceptance condition, not a
   confirmed overload without the actual loads.
   [Amphenol S6032C, page 2](https://cdn.amphenol-cs.com/media/wysiwyg/files/documentation/s6032c_rjhse.pdf)
2. Confirm actual blower current and D2's 1 A freewheel duty/temperature, plus
   Q1 heating at the intended 100 Hz PWM. R1 dissipates approximately 0.144 W
   at 12 V with the blower continuously enabled, within its 0.25 W nominal
   rating subject to temperature derating.
3. Verify combined WT32/servo 5 V load and startup against U2's rating, and
   count downstream capacitance as well as C3's 470 µF against the recorded
   820 µF capacitive-load limit. Confirm the owned ADC module supplies local
   100 nF bypassing and SDA/SCL pull-ups to its 3.3 V supply.
4. Meter-check harness orientation, 5807's 12 V output, relay NC/NO states
   and all custom-footprint samples before powering the complete assembly.
   Test source changes and adapter brownout: D3 delays coil release, and the
   relay circuit does not promise uninterrupted power or brownout supervision.

These checks do not request extra fuses, a different selector or new enclosure
openings. No physical measurements were performed in this review.

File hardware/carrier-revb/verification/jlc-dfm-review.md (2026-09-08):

# Independent JLCPCB bare-board DFM review

Reviewed 2026-09-06 against the current [JLCPCB rigid PCB capabilities](https://jlcpcb.com/capabilities/pcb-capabilities/). Scope: actual routed carrier geometry, current project rules and relevant local footprints; two-layer FR-4, 1.6 mm board, 1 oz copper. The initial independent audit was read-only. The design task subsequently authorized the limited regulator-area routing repairs described below.

**Result: no remaining measured fabrication-geometry blocker on the reviewed board.** The initial slot-ratio and silkscreen issues were corrected by the main design task and independently rechecked. The fabrication archive must still be generated from this reviewed board and visually checked for correct copper/mask/silk layers, outline and plated/non-plated drill separation. This is a bare-board manufacturing review, not module-fit or operating-load validation.

Reviewed PCB SHA256: `7d648c85aaa1fabd4f39074680c3daeb83a75353a57960b03cd88eaad8274764`.

Strict project SHA256: `814bd6b79383344938fb11cef374c5ab29d7d67091976e8c2353aa28831d35bf`.

## Findings corrected during review

- **J9 plated slots:** the original 0.80 × 1.50 mm slots had a 1.875:1 ratio. JLCPCB specifies slot length at least twice width. The three slots now measure **0.80 × 1.60 mm**, with minimum 0.45 mm annular ring. Local footprint drill definitions agree. Board-local coordinates (subtract KiCad X=100 mm, Y=50 mm) are pin 1 `(26.5,79.9)`, pin 2 `(26.5,85.8)`, pin 3 `(31.2,82.7)` mm.
- **Silkscreen:** original 0.80 mm text and 0.12 mm strokes were below the published printing guidance. All 41 visible footprint references now measure **1.00 mm high / 0.15 mm stroke**, and all 563 footprint silk primitives use 0.15 mm width. The project now requires 0.15 mm silk-to-pad clearance, 1.00 mm text height and 0.15 mm text stroke. Native DRC passes these rules.
- **U2 and J8 assembly holes:** the Traco footprint now represents the manufacturer's offset body and uses **Ø1.40 mm finished drills / Ø2.00 mm copper pads**, with 0.30 mm annular rings. U2 pin coordinates are `(17,70.75)`, `(19.54,70.75)` and `(22.08,70.75)` mm. J8's ten socket holes now use **Ø1.05 mm drills / Ø1.80 mm pads**, with 0.375 mm rings. The larger holes address actual lead/socket insertion rather than bare-board drilling limits.
- **Regulator-area routing:** the former thin ground route crossed corrected U2 pin 1 and was removed locally. A direct 2 mm front ground fanout and two parallel **Ø1.20/0.60 mm ground vias** at `(18,78.5)` and `(20,78.5)` reconnect the wide return pours. SERVO_SIG now detours around the left of U2, using two additional Ø0.80/0.40 mm transitions at `(23.4444,66.5)` and `(3,78)`. All servo track and via copper clears U2's maximum body. The full project check preserves the main 2 mm and J2 1.2 mm return corridors. No footprint/pad positions, circuit connections or mechanical keepouts changed during this local repair.

## Actual measurements

| Feature | Measured board | Result |
|---|---|---|
| Board outline | One closed 60 × 92 mm rectangle, four Edge.Cuts segments, 0.05 mm drawing stroke | Pass; no internal cutouts |
| Copper layers / thickness | Two / 1.60 mm | Standard rigid FR-4 geometry |
| Minimum track width | 0.30 mm; other routes 1.20 and 2.00 mm | Above 0.10 mm 1 oz manufacturing minimum |
| Minimum PTH annular ring | 0.30 mm, J4–J6 probe slots and U2 | Above 0.25 mm recommendation |
| RJ45 J2 pads | Ø1.50 mm copper / Ø0.89 mm drill; 0.305 mm ring | No thin-annulus issue remains |
| Probe slots J4–J6 | Nine 0.50 × 1.50 mm plated slots, 0.30 mm ring | At the supported two-layer minimum width; 3:1 ratio |
| Barrel slots J9 | Three 0.80 × 1.60 mm plated slots | Meets 2:1 ratio |
| Vias | Eleven Ø0.80/0.40 mm and five Ø1.20/0.60 mm pad/drill pairs | 0.20/0.30 mm rings; no microvias |
| Closest drill edges | U2 and Q1 adjacent holes: approximately 1.140 mm; J2 same-row holes: 1.142 mm | Above 0.45 mm PTH hole spacing |
| Closest foreign trace to via hole | Approximately 0.502 mm | Above 0.20 mm minimum |
| Closest foreign trace to component PTH hole | Approximately 0.621 mm, J2 pin 8 | Above 0.28 mm minimum |
| Closest foreign trace to NPTH | Approximately 0.584 mm, left J2 locating peg | Above 0.20 mm minimum |
| Mask expansion | Zero; pad and mask aperture 1:1 | Supported by current JLCPCB LDI process |
| Narrowest mask web | Approximately 0.313 mm, J2 pins 1/2 | Above 0.10 mm green and 0.13 mm black/white guidance |
| Copper-to-outline clearance | Current project requires 0.50 mm; native DRC passes | Above 0.20 mm routed-edge minimum |

The mask web calculation uses native KiCad pad polygons; drill/trace distances use native shape collision queries with 0.001 mm search resolution. Reported distances are rounded approximations. Vias are tented on both sides in the PCB settings; they are not specified as epoxy-filled or copper-capped. Mounting and locating holes are intentionally NPTH without copper annular pads.

## Regulator layout tradeoff

Traco's generic instruction to avoid routing traces under the converter is **not fully implemented**. The original low-impedance, 2 mm-wide WALL_12V front trace remains centered at X=26.5 mm. Its copper overlaps the maximum tolerated converter body over X=25.50…27.04 mm, Y=68.81…77.41 mm: a **1.54 mm-wide edge strip**. Against the nominal body the strip is 1.04 mm wide. Moving this feed to the back obstructed the alternative ground return and left a roughly 1.7 mm corridor between the R15 AIN2 pad and K1 NO pad. Retaining the original front route preserves the stronger return path with a bounded repair. The servo signal is outside the maximum body, while necessary direct VIN, VOUT and ground fanouts remain beneath the converter. This is a documented engineering tradeoff, not a claim of full compliance with the generic Traco layout note; loaded regulation and interference require prototype measurement.

## Verification and reproducibility

Final native KiCad checks against the restored strict project settings: **0 DRC violations, 0 unconnected items, 0 ERC violations and 0 schematic-parity issues**. The current [verification summary](summary.json), [DRC report](drc.json) and [ERC report](erc.json) match the PCB, schematic and project hashes. Final board: **314 tracks and 16 vias**. The independent native geometry measurement was repeated on this final PCB hash; its snapshot is `/tmp/pitclaw-jlc-measurements.json` and its retained measurement log is `work/jlc-release/final-dfm-measurements.log`.

The local custom footprints now carry the corrected hole geometry and 0.15 mm silk strokes. Any future update from original footprint libraries must retain these corrections and rerun the strict manufacturing checks before regenerating fabrication files. Saving a board loaded under a different basename was found to reset the live KiCad project to default rules; the release task restored the strict project and reran checks. The final project hash must match the verification summary before CAM export.

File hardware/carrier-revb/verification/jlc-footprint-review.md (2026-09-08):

# Footprint audit for the first JLCPCB order

Reviewed 2026-09-06 against the native PCB, custom library footprints and the
manufacturer drawings below. This review made no CAD changes.

Reviewed PCB SHA256:
`7d648c85aaa1fabd4f39074680c3daeb83a75353a57960b03cd88eaad8274764`.
The inspected PCB contains 314 tracks and 16 vias. Coordinates below use the
60 × 92 mm board frame, with KiCad's (100,50) mm drawing offset removed.
The final strict-rule pass restored project rules, refilled ground copper and
moved J9's reference text. A native comparison confirmed that the reviewed
U2/J8/J9 footprint geometry, all tracks and all vias remain unchanged. The matching
official verification summary reports zero ERC, DRC, schematic-parity and
unconnected-item findings.

## Ordering findings

**The confirmed U2 footprint defects are corrected.** The former Ø1.0 mm holes
did not accommodate the full published pin tolerance. Traco specifies 0.64 mm square
pins with ±0.1 mm pin tolerance: the maximum diagonal is
`sqrt(2) × 0.74 = 1.047 mm`, larger than the former nominal hole. Its body was
also incorrectly centered on the pin row. With pins 1–3 running along +X, the
nominal body is X −4.46…9.54 mm, Y −1.44…6.16 mm relative to pin 1.

The sealed PCB and local footprint now use Ø1.4 mm holes with 2.0 mm pads and
the corrected body. U2's pin-1 anchor is (17,70.75) mm; its nominal body occupies
X12.54…26.54 / Y69.31…76.91 mm. The courtyard is
X11.79…27.29 / Y68.56…77.66 mm, including the ±0.5 mm body tolerance and
additional clearance. The position is 0.75 mm north of the former anchor to
accommodate the corrected body near J2. These dimensions and orientation agree
with KiCad 9's exact `Converter_DCDC_TRACO_TSR2-24xxN_TSR2-24xxxN_THT`
footprint. Pins remain 1=VIN, 2=GND, 3=VOUT with 2.54 mm pitch.
[Traco's current manufacturer datasheet, page 4](https://www.mouser.com/datasheet/3/1230/1/tsr2n_datasheet.pdf)

**U2's under-body routing is an explicit layout tradeoff.** Traco advises
avoiding PCB traces beneath the converter. The unrelated servo route has been
moved outside the conservatively expanded body rectangle
X12.04…27.04 / Y68.81…77.41 mm; the closest servo track copper is 0.76 mm away.
No ADC, probe or I²C signal route crosses this rectangle. Direct converter
supply/ground fanouts remain, as does the 2.0 mm F.Cu WALL_12V trunk centered
at X26.5 mm. That trunk overlaps the maximum body by a 1.54 mm edge strip,
X25.5…27.04 / Y68.81…77.41 mm. It was deliberately retained to preserve the
broad ground return; this does **not** fully follow Traco's routing guidance.
This is a prototype layout limitation, not a demonstrated mechanical fit
failure. Two Ø1.2/0.6 mm GND vias at (18,78.5) and (20,78.5) mm lie outside
the maximum body. These statements come from an independent read of the sealed
PCB's actual track geometry, including track width.

**J9's CAM issue has been corrected in the inspected native PCB.** Tensility
specifies 0.8 × 1.5 mm slots; the board now extends their long dimension to
1.6 mm to meet JLCPCB's slot aspect-ratio requirement. Slot direction and all
three centers remain correct. [Tensility drawing, page 1](https://tensility.s3.us-west-2.amazonaws.com/imports/product_spec_sheets/54-00133.pdf),
[JLCPCB drilling capabilities](https://jlcpcb.com/capabilities/pcb-capabilities)

**J8's owned module is still an unqualified fit assumption.** The carrier's
socket is a defined Sullins part, and its 2.54 mm pitch / 22.86 mm end-to-end pin
span is correct. Sullins recommends Ø1.02 mm holes; all ten holes in the sealed
PCB and local footprint now use Ø1.05 mm, exceeding that nominal recommendation.
[Sullins manufacturer drawing, page 2](https://mm.digikey.com/Volume0/opasdata/d220001/medias/docus/937/Female_Headers.100_DS.pdf)

The module above that socket has no identified manufacturer or controlled
mechanical drawing. The user-linked Components101 page provides a generic
module model and pin labels, but does not establish the owned board's exact
header-to-edge offsets or assembled insertion height. Its linked chip datasheet
does not define those module dimensions. A matching nominal outline cannot
establish that two anonymous blue modules are mechanically identical.
[User-identified module reference](https://components101.com/modules/ads1115-module-with-programmable-gain-amplifier)

No confirmed footprint defect remains in the sealed PCB. With the final
strict-rule DRC passing, and subject to the separate archived-CAM checks,
this supports a **small bare-PCB prototype order**. It does not establish guaranteed drop-in fit of the
owned ADC module. If avoiding a possible board respin is essential, confirm
the module's 22.86 mm first-to-last pin span, pin order, header-to-edge offsets
and fully seated height before ordering. Electrical bring-up measurements are
separate from these dimensions that can affect PCB placement.
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

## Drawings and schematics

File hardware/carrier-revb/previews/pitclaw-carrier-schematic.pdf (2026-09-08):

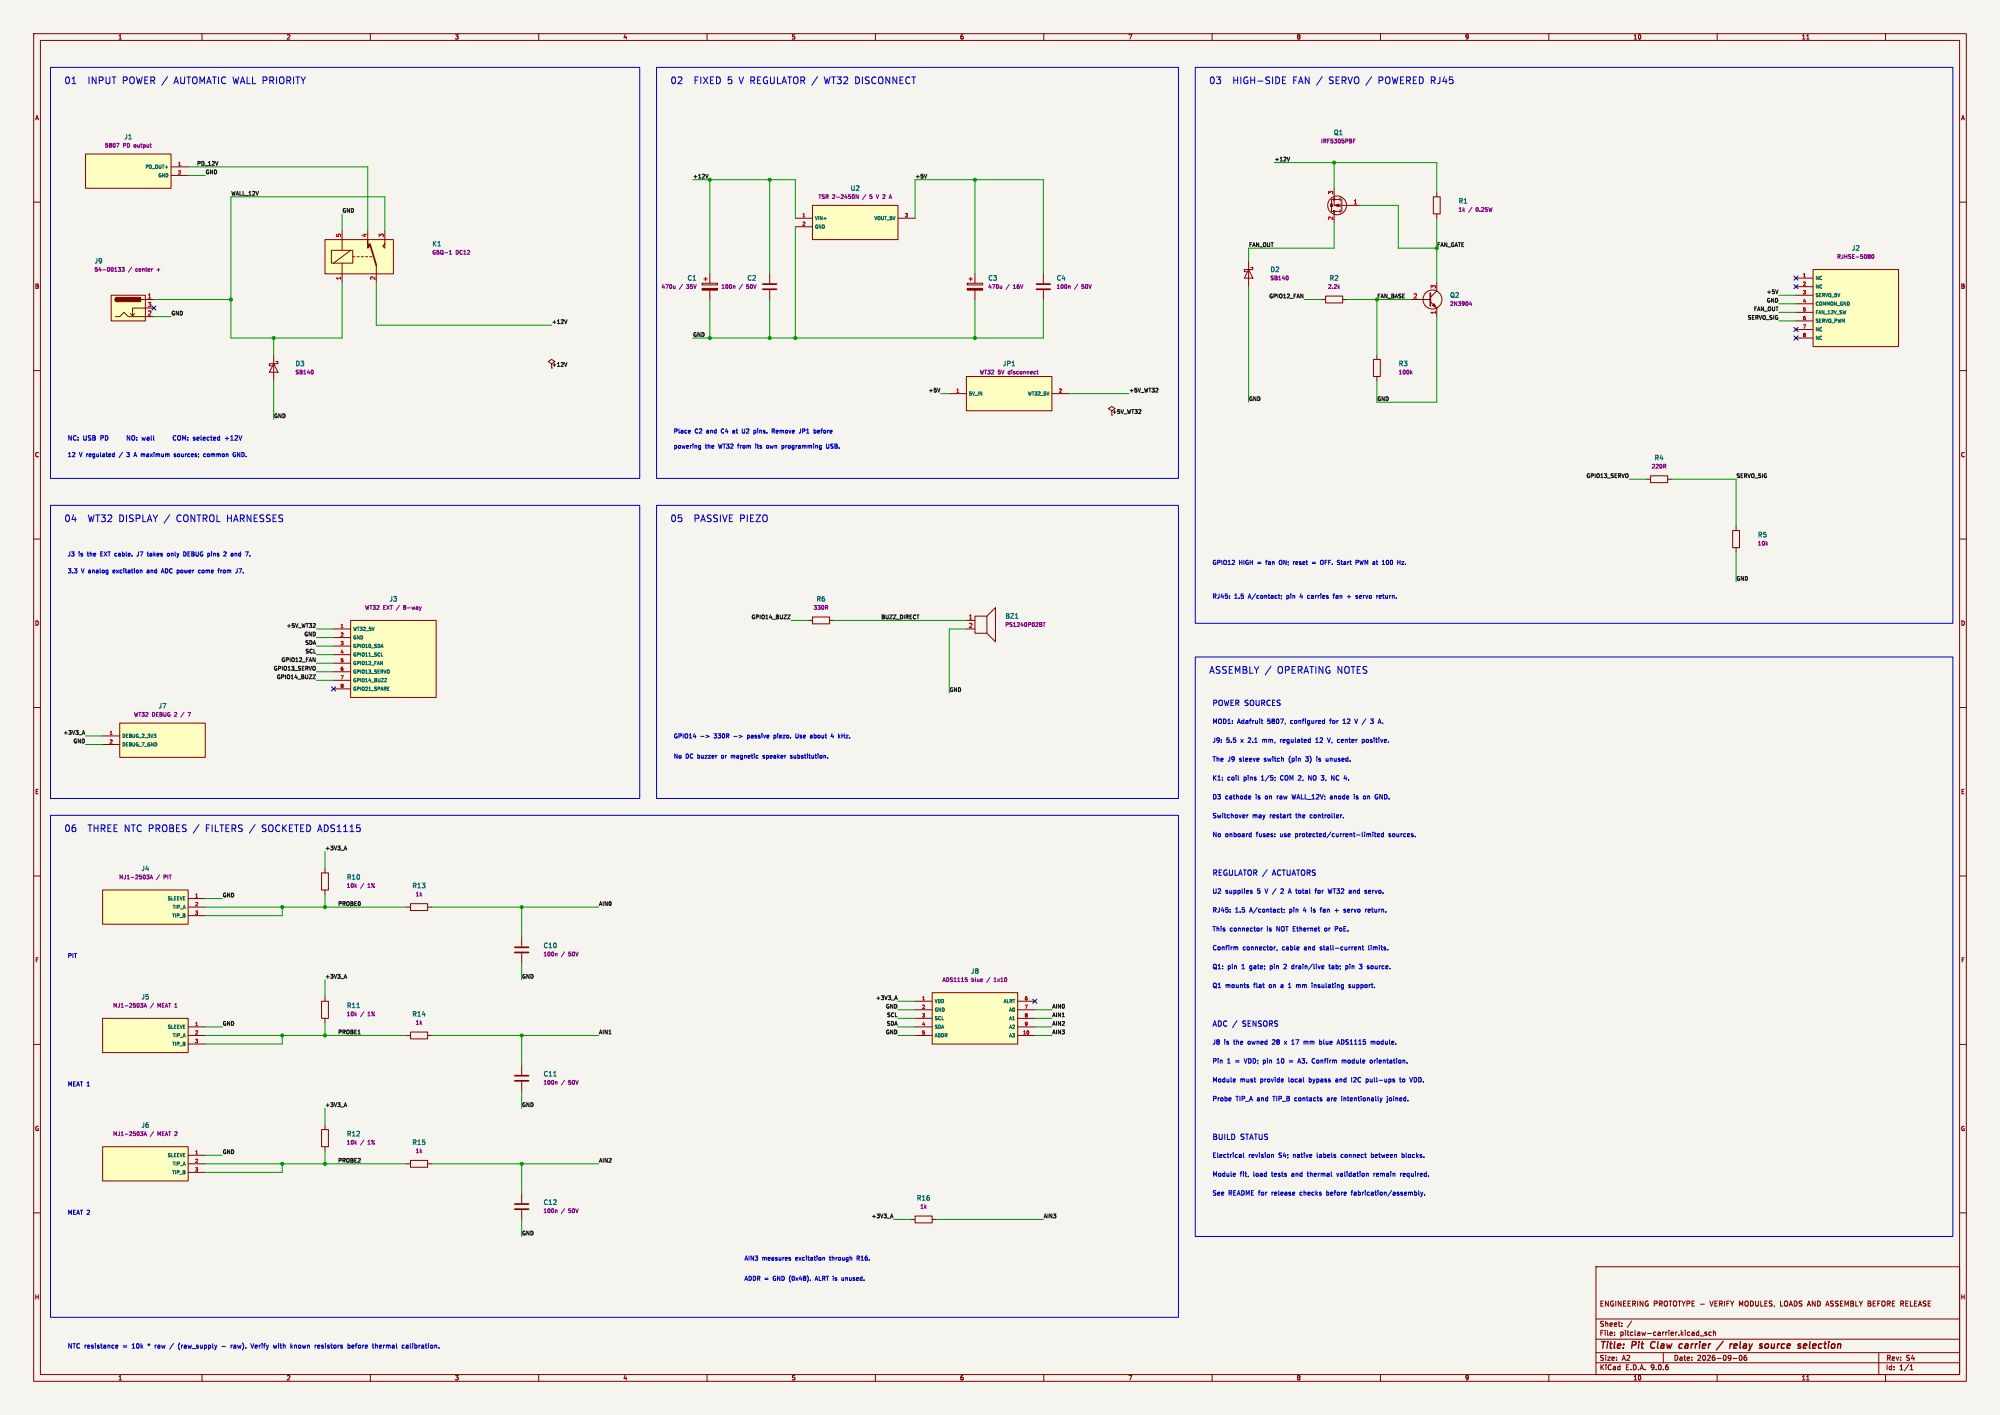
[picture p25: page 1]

01 INPUT POWER / AUTOMATIC WALL PRIORITY
5807 PD output1

03 HIGH-SIDE FAN / SERVO / POWERED RJ45

Place C2 and C4 at U2 pins. Remove JP1 before

06 THREE NTC PROBES / FILTERS / SOCKETED ADS1115

See README for release checks before fabrication/assembly.

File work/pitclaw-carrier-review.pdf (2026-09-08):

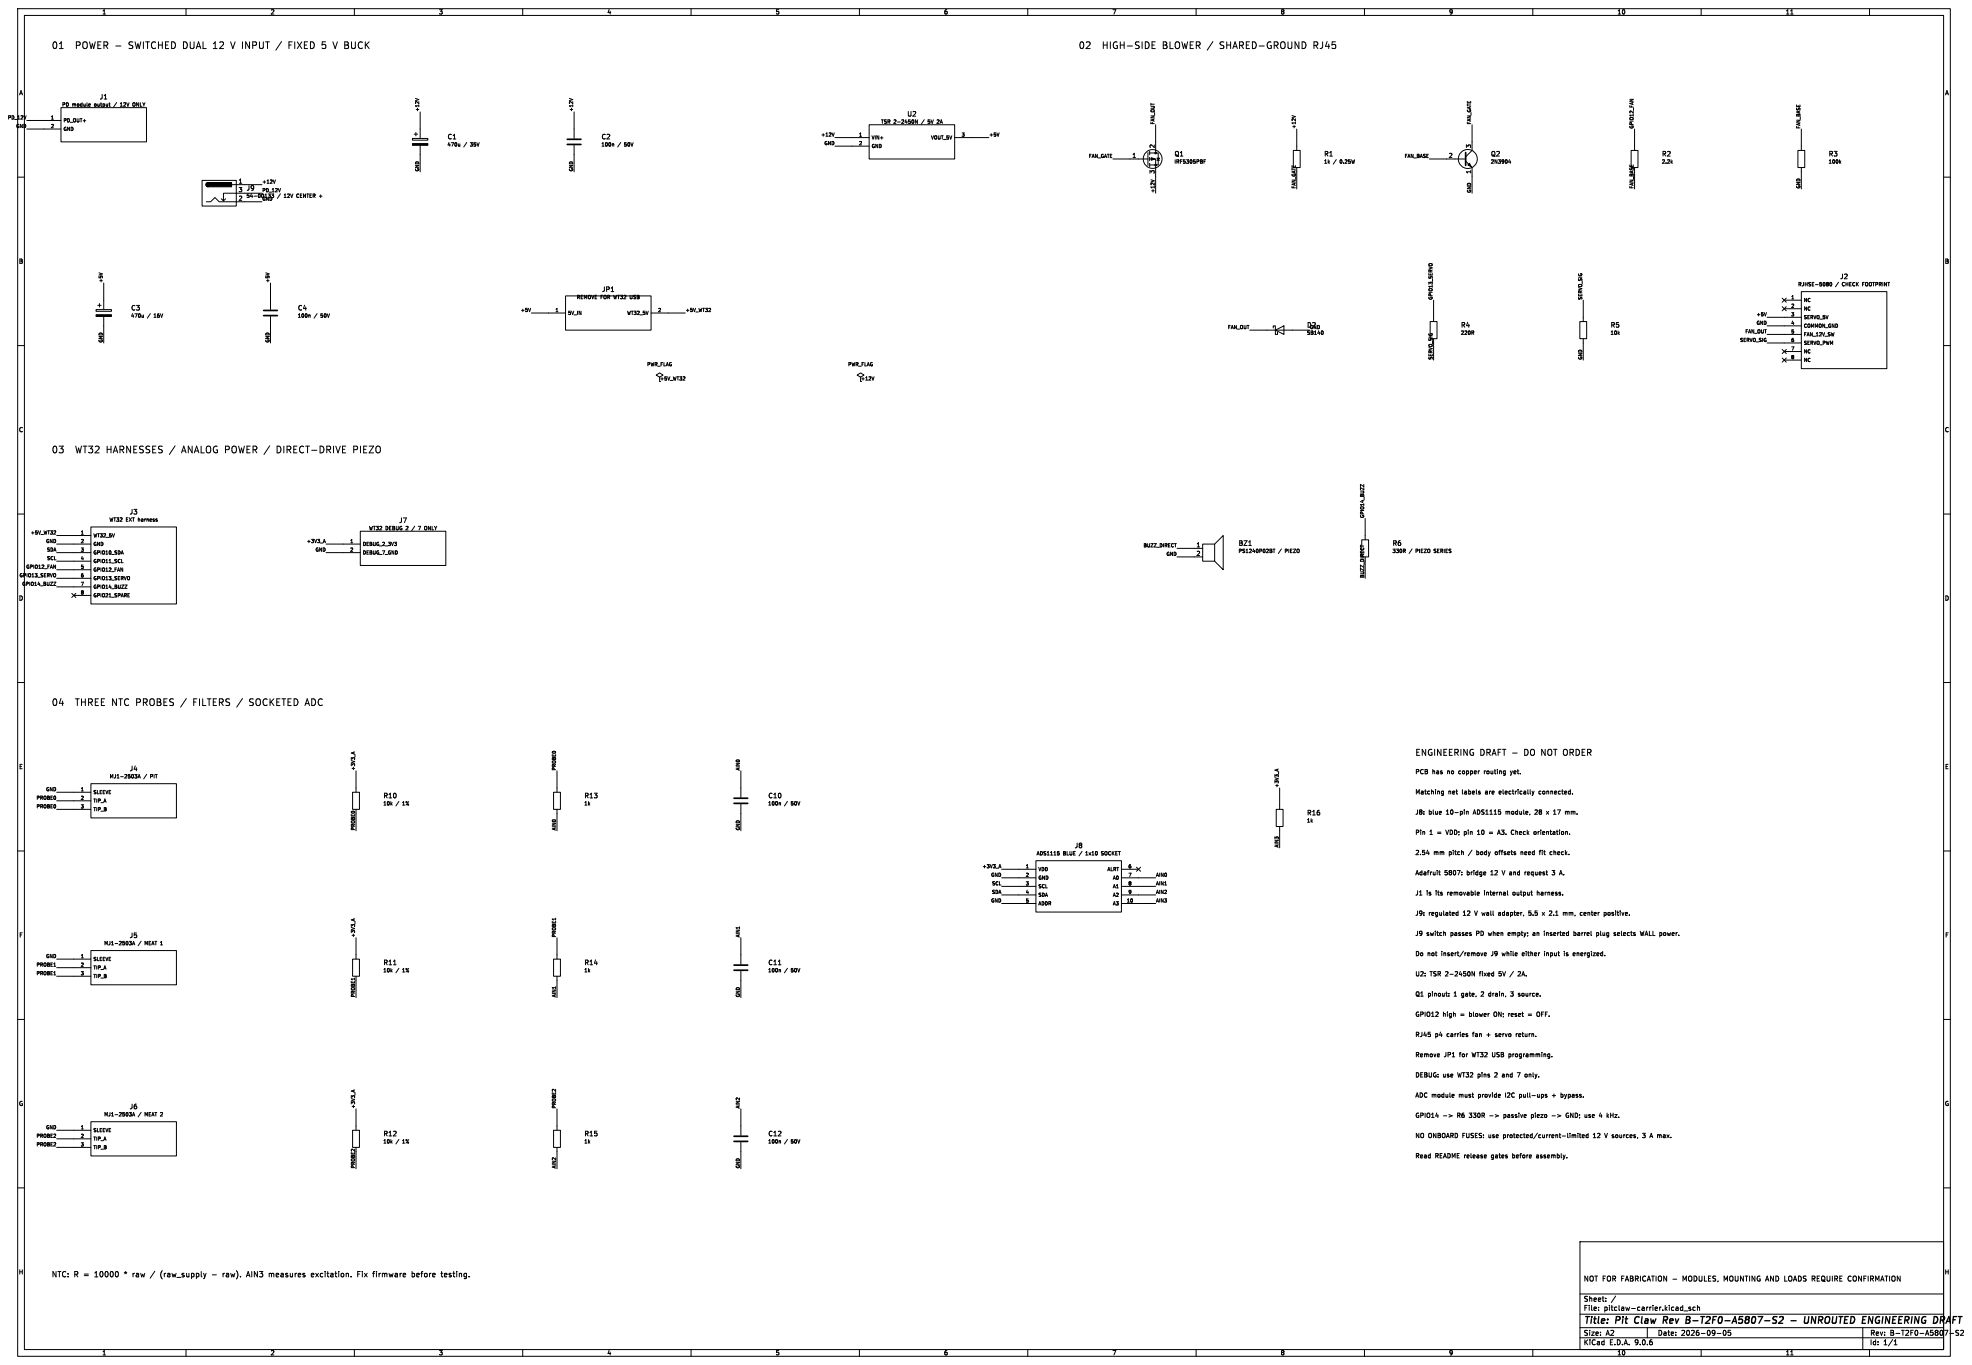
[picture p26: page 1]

01 POWER - SWITCHED DUAL 12 V INPUT / FIXED 5 V BUCK

02 HIGH-SIDE BLOWER / SHARED-GROUND RJ45

PD module output / 12V ONLY

03 WT32 HARNESSES / ANALOG POWER / DIRECT-DRIVE PIEZO
GND GPIO14_BUZZ GPIO13_SERVO

2.54 mm pitch / body offsets need fit check. Adafruit 5807: bridge 12 V and request 3 A. 04 THREE NTC PROBES / FILTERS / SOCKETED ADC

ENGINEERING DRAFT - DO NOT ORDER

PCB has no copper routing yet.

Pin 1 = VDD; pin 10 = A3. Check orientation.

Read README release gates before assembly.

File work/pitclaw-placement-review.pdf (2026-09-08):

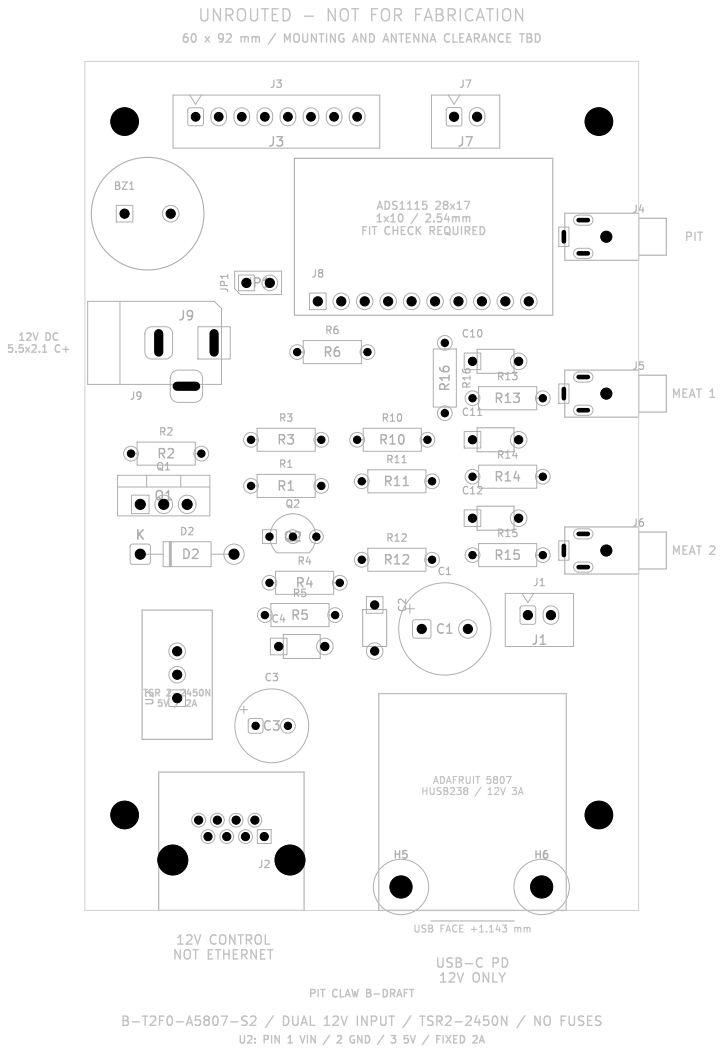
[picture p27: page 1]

ADAFRUIT 5807 HUSB238 / 12V 3A UNROUTED - NOT FOR FABRICATION

60 x 92 mm / MOUNTING AND ANTENNA CLEARANCE TBD

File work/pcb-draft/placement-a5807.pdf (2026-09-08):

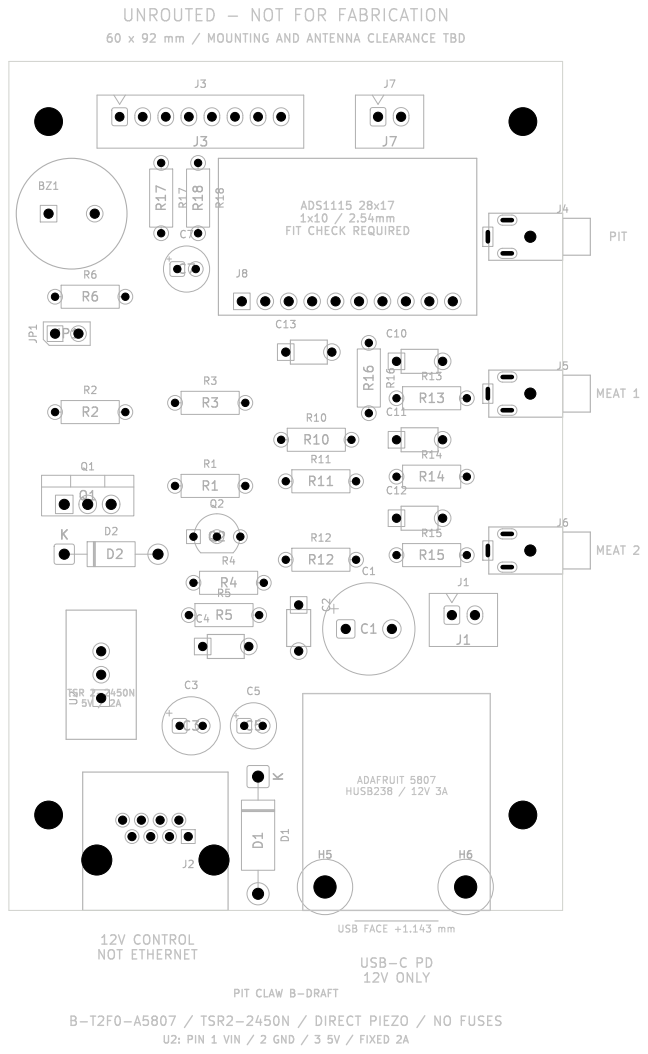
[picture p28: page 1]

60 x 92 mm / MOUNTING AND ANTENNA CLEARANCE TBD UNROUTED - NOT FOR FABRICATION

PIT CLAW B-DRAFT U2: PIN 1 VIN / 2 GND / 3 5V / FIXED 2A

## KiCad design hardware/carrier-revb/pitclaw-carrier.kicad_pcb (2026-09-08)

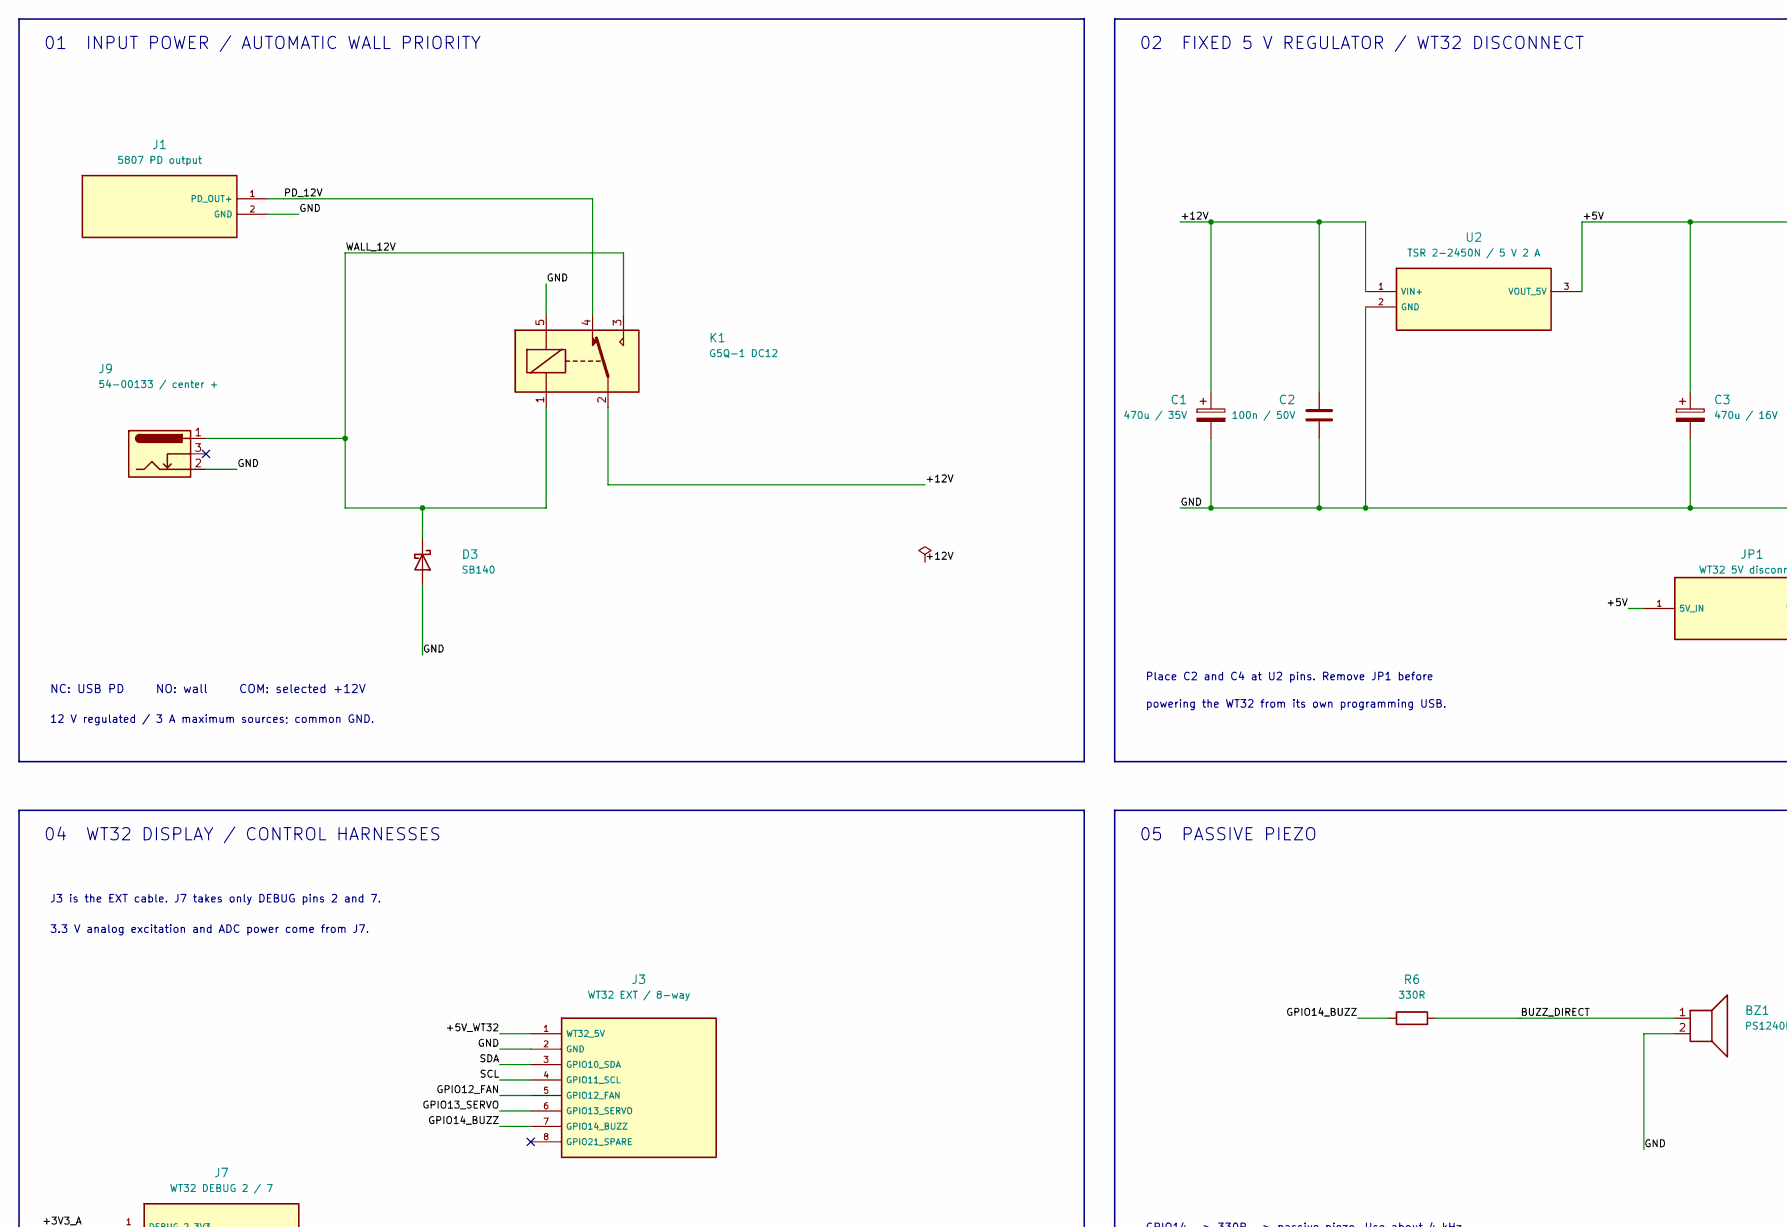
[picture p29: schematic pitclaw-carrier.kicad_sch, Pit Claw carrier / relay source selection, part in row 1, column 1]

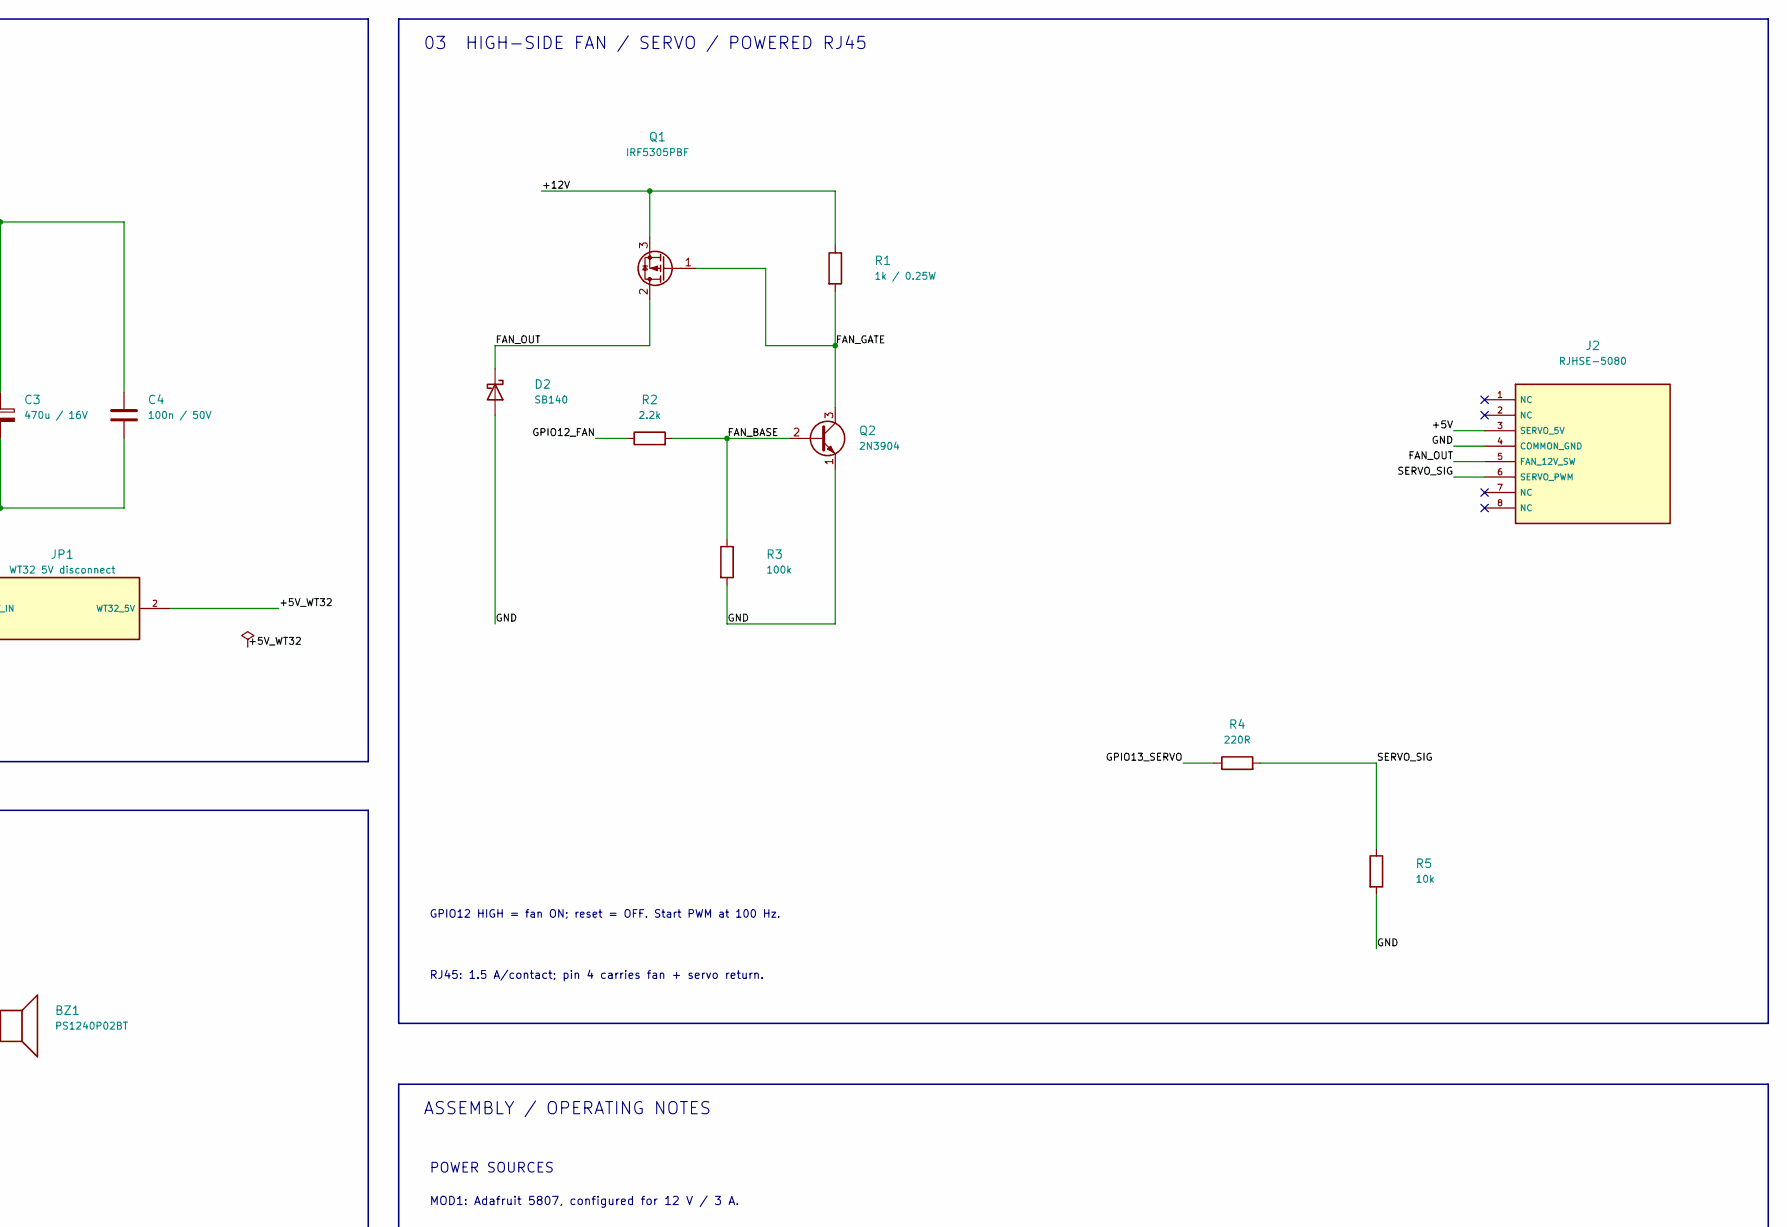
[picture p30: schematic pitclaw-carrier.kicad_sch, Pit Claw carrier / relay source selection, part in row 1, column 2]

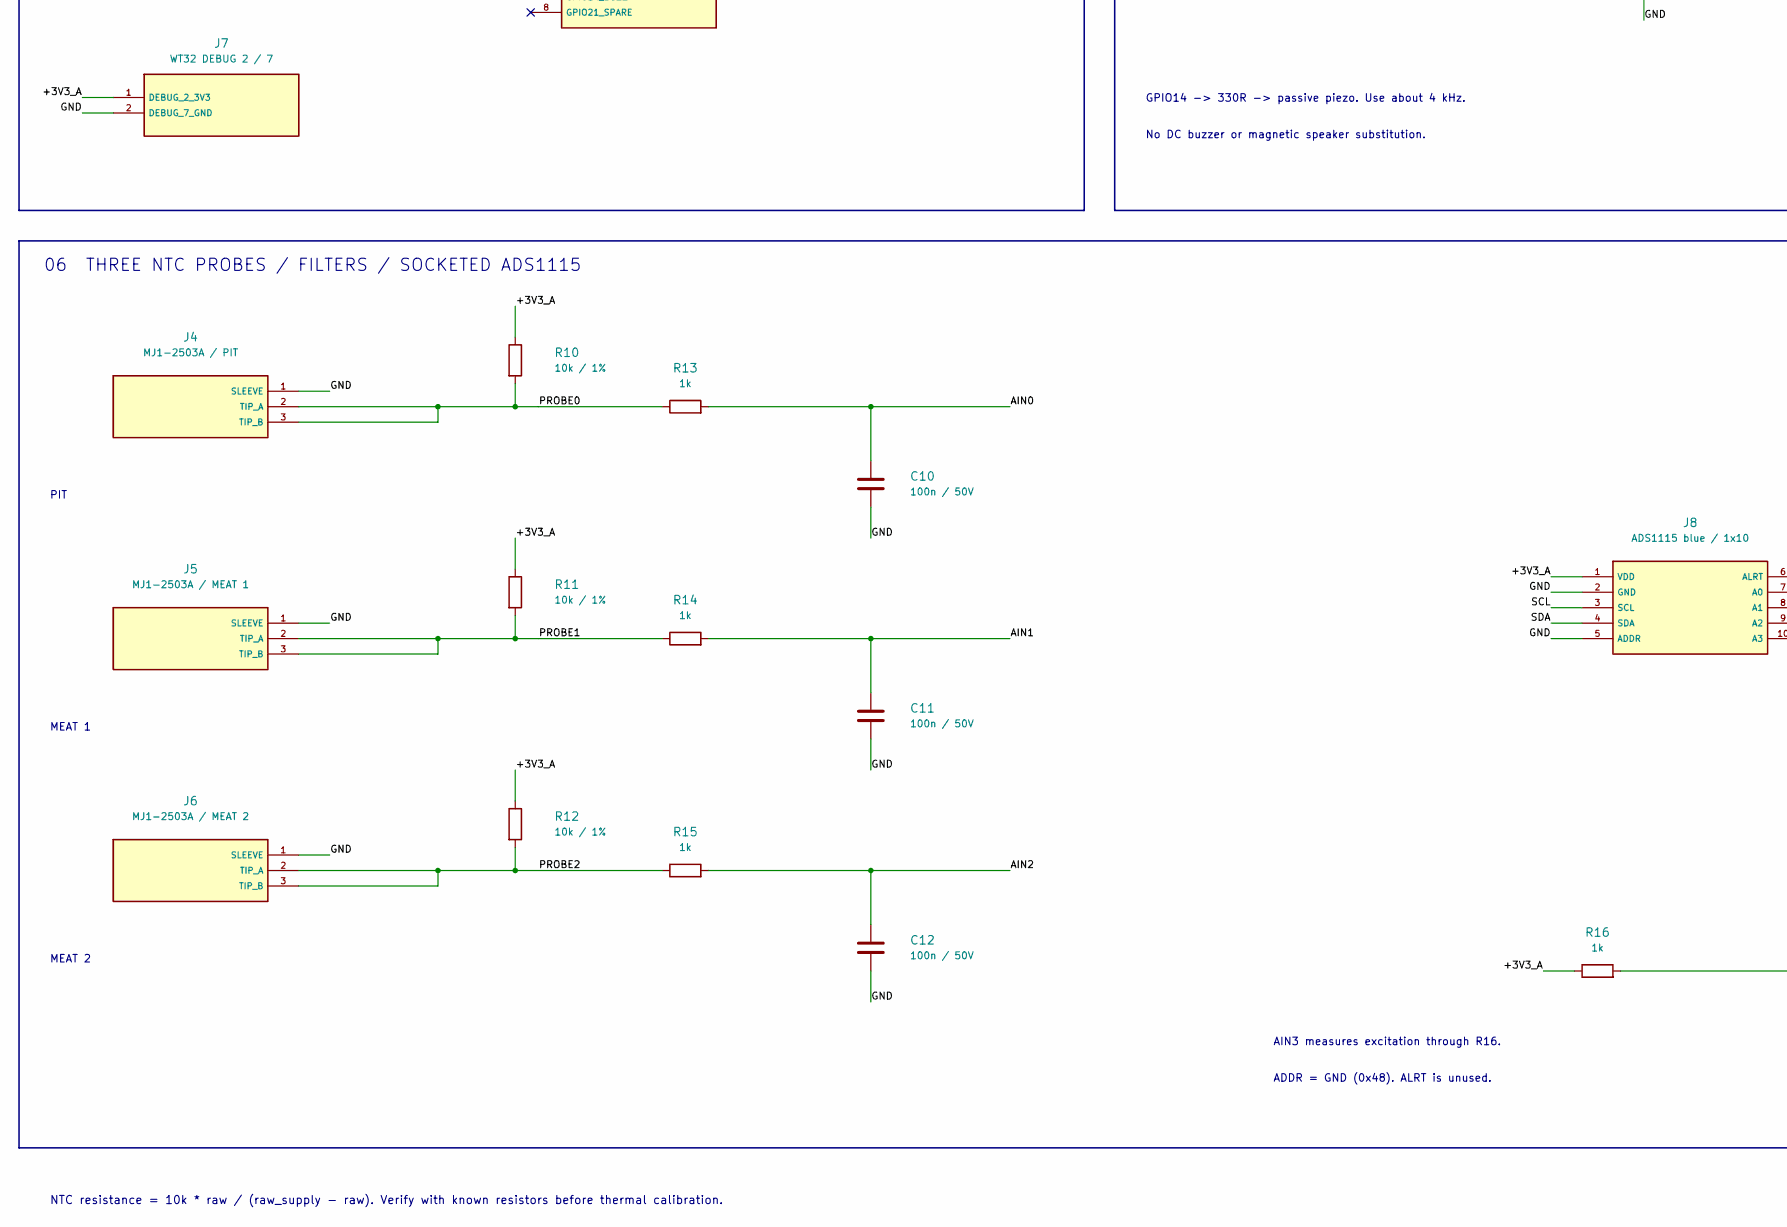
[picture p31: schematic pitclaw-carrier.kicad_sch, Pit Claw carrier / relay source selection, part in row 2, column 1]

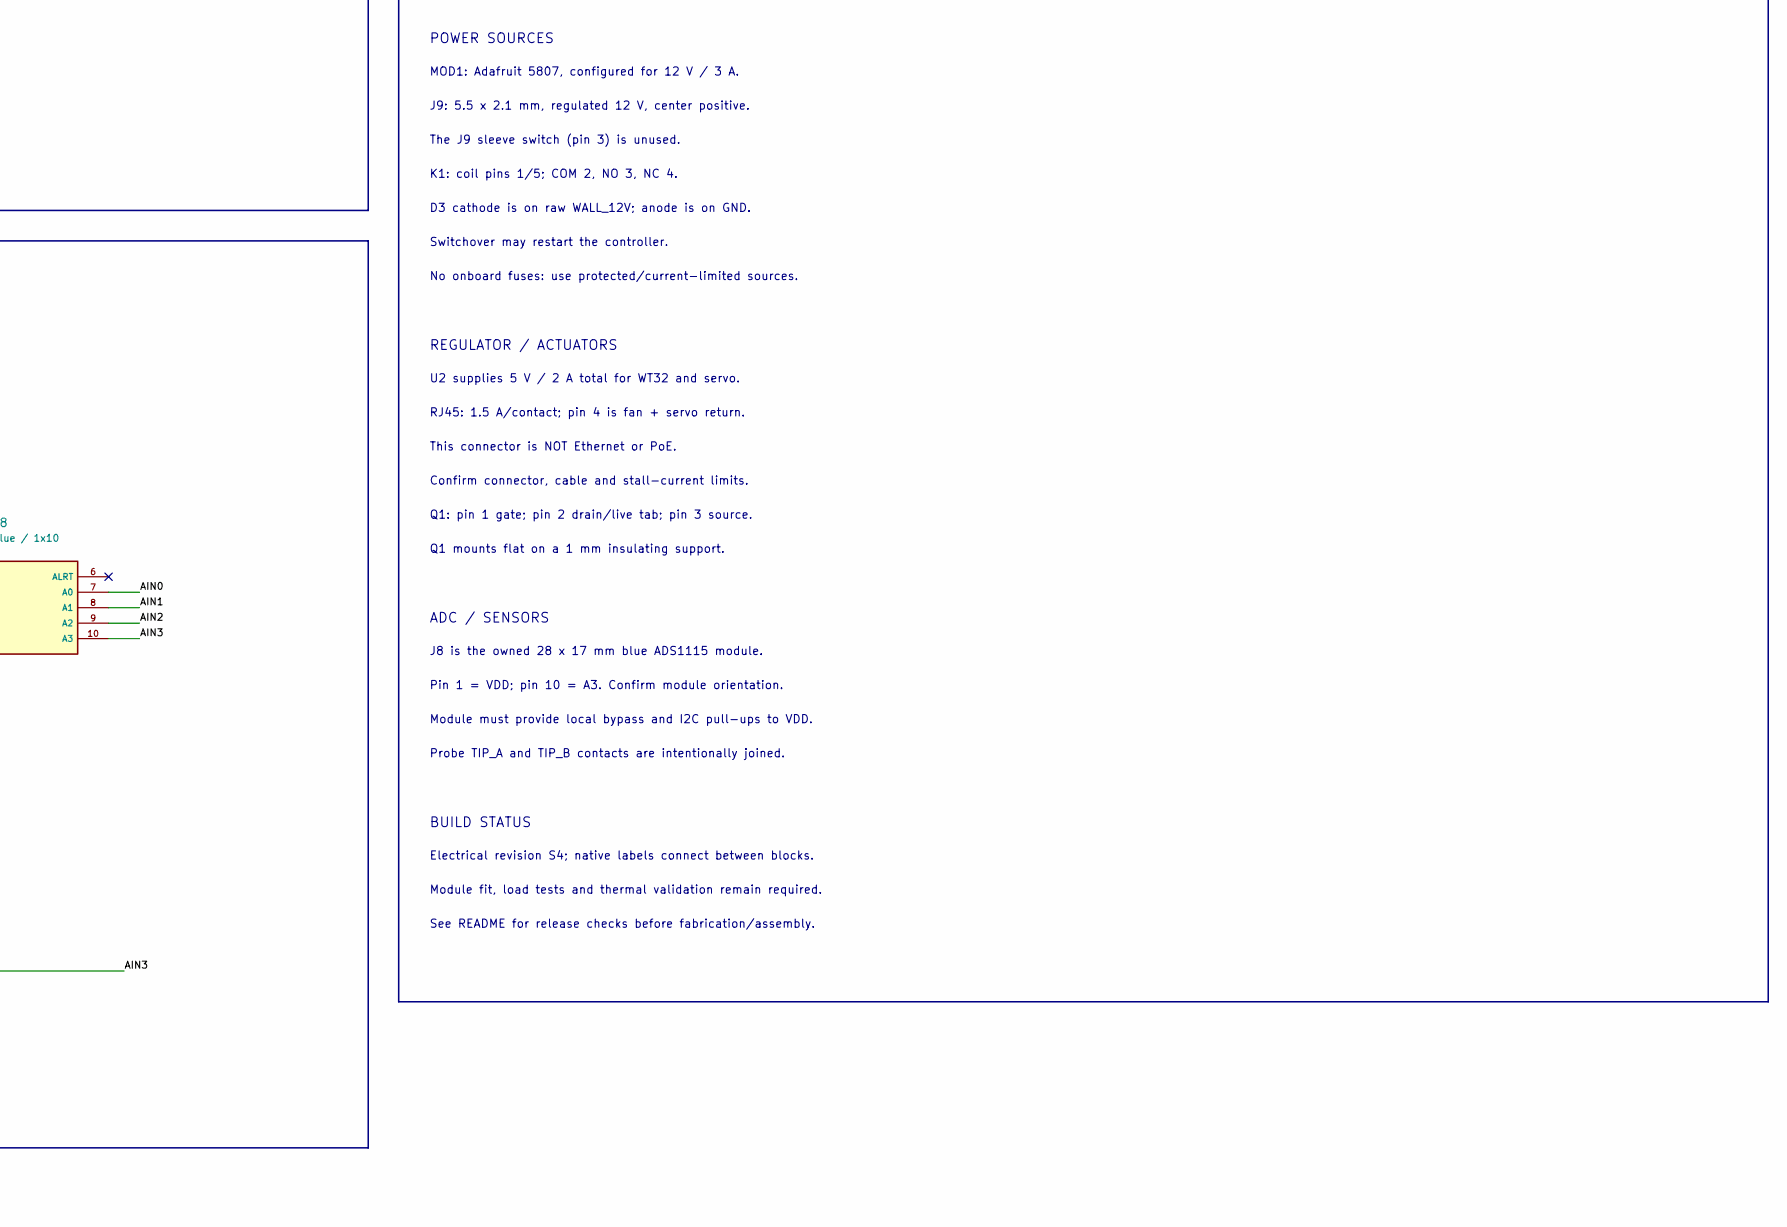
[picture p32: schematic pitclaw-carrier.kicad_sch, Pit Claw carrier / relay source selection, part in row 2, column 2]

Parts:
BZ1: PS1240P02BT / PIEZO; Piezo_TDK_PS1240P02BT_D12.2_P5; MPN PS1240P02BT; DigiKey 445-2525-1-ND
C1: 470u / 35V; CP_Radial_D10.0mm_P5.00mm; MPN 35PX470MEFC10X12.5; DigiKey 1189-1280-ND
C2, C4, C10, C11, C12: 100n / 50V; C_TDK_FG28X7R1H104KNT06_P5; MPN FG28X7R1H104KNT06; DigiKey 445-173588-1-ND
C3: 470u / 16V; CP_Radial_D8.0mm_P3.50mm; MPN 16ZLH470MEFC8X11.5; DigiKey 1189-1859-ND
D2: SB140; D_DO-41_SOD81_P10.16mm_Horizontal; MPN SB140; DigiKey 1655-SB140CT-ND
D3: SB140 / COIL FLYBACK; D_DO-41_SOD81_P10.16mm_Horizontal; MPN SB140; DigiKey 1655-SB140CT-ND
J1: PD module output / 12V ONLY; JST_XH_B2B-XH-A_1x02_P2.50mm_Vertical; MPN B2B-XH-A; DigiKey 455-B2B-XH-A-ND
J2: RJHSE-5080 / CHECK FOOTPRINT; RJHSE-5080_DRAFT; MPN RJHSE5080; DigiKey 664-RJHSE5080-ND
J3: WT32 EXT harness; JST_XH_B8B-XH-A_1x08_P2.50mm_Vertical; MPN B8B-XH-A; DigiKey 455-B8B-XH-A-ND
J4: MJ1-2503A / PIT; MJ1-2503A; MPN MJ1-2503A; DigiKey CP1-2503AM-ND
J5: MJ1-2503A / MEAT 1; MJ1-2503A; MPN MJ1-2503A; DigiKey CP1-2503AM-ND
J6: MJ1-2503A / MEAT 2; MJ1-2503A; MPN MJ1-2503A; DigiKey CP1-2503AM-ND
J7: WT32 DEBUG 2 / 7 ONLY; JST_XH_B2B-XH-A_1x02_P2.50mm_Vertical; MPN B2B-XH-A; DigiKey 455-B2B-XH-A-ND
J8: ADS1115 BLUE / 1x10 SOCKET; ADS1115_Blue_1x10_DRAFT; MPN PPPC101LFBN-RC; DigiKey S7043-ND
J9: 54-00133 / 12V CENTER +; Tensility_54-00133_Horizontal; MPN 54-00133; DigiKey 839-54-00133-ND
JP1: REMOVE FOR WT32 USB; PinHeader_1x02_P2.54mm_Vertical; MPN 68000-102HLF; DigiKey 609-3500-ND
K1: G5Q-1 DC12 / WALL PRIORITY; Omron_G5Q1_SPDT_MaxBody; MPN G5Q-1 DC12; DigiKey Z221-ND
Q1: IRF5305PBF; IRF5305_TO220_Horizontal_TabDown; MPN IRF5305PBF; DigiKey IRF5305PBF-ND
Q2: 2N3904; TO-92_Inline_Wide; MPN 2N3904BU; DigiKey 2N3904FS-ND
R1: 1k / 0.25W; R_Axial_DIN0207_L6.3mm_D2.5mm_P7.62mm_Horizontal; MPN MFR-25FBF52-1K; DigiKey 1.00KXBK-ND
R2: 2.2k; R_Axial_DIN0207_L6.3mm_D2.5mm_P7.62mm_Horizontal; MPN MFR-25FBF52-2K2; DigiKey MFR-25FBF52-2K2-ND
R3: 100k; R_Axial_DIN0207_L6.3mm_D2.5mm_P7.62mm_Horizontal; MPN MFR-25FBF52-100K; DigiKey 100KXBK-ND
R4: 220R; R_Axial_DIN0207_L6.3mm_D2.5mm_P7.62mm_Horizontal; MPN MFR-25FBF52-220R; DigiKey MFR-25FBF52-220R-ND
R5: 10k; R_Axial_DIN0207_L6.3mm_D2.5mm_P7.62mm_Horizontal; MPN MFR-25FBF52-10K; DigiKey 10.0KXBK-ND
R6: 330R / PIEZO SERIES; R_Axial_DIN0207_L6.3mm_D2.5mm_P7.62mm_Horizontal; MPN MFR-25FBF52-330R; DigiKey MFR-25FBF52-330R-ND
R10, R11, R12: 10k / 1%; R_Axial_DIN0207_L6.3mm_D2.5mm_P7.62mm_Horizontal; MPN MFR-25FBF52-10K; DigiKey 10.0KXBK-ND
R13, R14, R15, R16: 1k; R_Axial_DIN0207_L6.3mm_D2.5mm_P7.62mm_Horizontal; MPN MFR-25FBF52-1K; DigiKey 1.00KXBK-ND
U2: TSR 2-2450N / 5V 2A; TRACO_TSR_2N_SIP3; MPN TSR 2-2450N; DigiKey 1951-TSR2-2450N-ND

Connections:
/+3V3_A: J7.1 (DEBUG_2_3V3), J8.1 (VDD), R10.1, R11.1, R12.1, R16.1
/+5V: C3.1, C4.1, J2.3 (SERVO_5V), JP1.1 (5V_IN), U2.3 (VOUT_5V)
/+5V_WT32: J3.1 (WT32_5V), JP1.2 (WT32_5V)
/+12V: C1.1, C2.1, K1.2, Q1.3 (S), R1.1, U2.1 (VIN+)
/AIN0: C10.1, J8.7 (A0), R13.2
/AIN1: C11.1, J8.8 (A1), R14.2
/AIN2: C12.1, J8.9 (A2), R15.2
/AIN3: J8.10 (A3), R16.2
/BUZZ_DIRECT: BZ1.1, R6.2
/FAN_BASE: Q2.2 (B), R2.2, R3.1
/FAN_GATE: Q1.1 (G), Q2.3 (C), R1.2
/FAN_OUT: D2.1 (K), J2.5 (FAN_12V_SW), Q1.2 (D)
/GND: BZ1.2, C1.2, C2.2, C3.2, C4.2, C10.2, C11.2, C12.2, D2.2 (A), D3.2 (A), J1.2 (GND), J2.4 (COMMON_GND), J3.2 (GND), J4.1 (SLEEVE), J5.1 (SLEEVE), J6.1 (SLEEVE), J7.2 (DEBUG_7_GND), J8.2 (GND), J8.5 (ADDR), J9.2, K1.5, Q2.1 (E), R3.2, R5.2, U2.2 (GND)
/GPIO12_FAN: J3.5 (GPIO12_FAN), R2.1
/GPIO13_SERVO: J3.6 (GPIO13_SERVO), R4.1
/GPIO14_BUZZ: J3.7 (GPIO14_BUZZ), R6.1
/PD_12V: J1.1 (PD_OUT+), K1.4
/PROBE0: J4.2 (TIP_A), J4.3 (TIP_B), R10.2, R13.1
/PROBE1: J5.2 (TIP_A), J5.3 (TIP_B), R11.2, R14.1
/PROBE2: J6.2 (TIP_A), J6.3 (TIP_B), R12.2, R15.1
/SCL: J3.4 (GPIO11_SCL), J8.3 (SCL)
/SDA: J3.3 (GPIO10_SDA), J8.4 (SDA)
/SERVO_SIG: J2.6 (SERVO_PWM), R4.2, R5.1
/WALL_12V: D3.1 (K), J9.1, K1.1, K1.3

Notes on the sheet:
01 INPUT POWER / AUTOMATIC WALL PRIORITY
NC: USB PD NO: wall COM: selected +12V
12 V regulated / 3 A maximum sources; common GND.
02 FIXED 5 V REGULATOR / WT32 DISCONNECT
Place C2 and C4 at U2 pins. Remove JP1 before
powering the WT32 from its own programming USB.
03 HIGH-SIDE FAN / SERVO / POWERED RJ45
GPIO12 HIGH = fan ON; reset = OFF. Start PWM at 100 Hz.
RJ45: 1.5 A/contact; pin 4 carries fan + servo return.
04 WT32 DISPLAY / CONTROL HARNESSES
J3 is the EXT cable. J7 takes only DEBUG pins 2 and 7.
3.3 V analog excitation and ADC power come from J7.
05 PASSIVE PIEZO
GPIO14 -> 330R -> passive piezo. Use about 4 kHz.
No DC buzzer or magnetic speaker substitution.
06 THREE NTC PROBES / FILTERS / SOCKETED ADS1115
PIT
MEAT 1
MEAT 2
AIN3 measures excitation through R16.
ADDR = GND (0x48). ALRT is unused.
NTC resistance = 10k * raw / (raw_supply - raw). Verify with known resistors before thermal calibration.
ASSEMBLY / OPERATING NOTES
POWER SOURCES
MOD1: Adafruit 5807, configured for 12 V / 3 A.
J9: 5.5 x 2.1 mm, regulated 12 V, center positive.
The J9 sleeve switch (pin 3) is unused.
K1: coil pins 1/5; COM 2, NO 3, NC 4.
D3 cathode is on raw WALL_12V; anode is on GND.
Switchover may restart the controller.
No onboard fuses: use protected/current-limited sources.
REGULATOR / ACTUATORS
U2 supplies 5 V / 2 A total for WT32 and servo.
RJ45: 1.5 A/contact; pin 4 is fan + servo return.
This connector is NOT Ethernet or PoE.
Confirm connector, cable and stall-current limits.
Q1: pin 1 gate; pin 2 drain/live tab; pin 3 source.
Q1 mounts flat on a 1 mm insulating support.
ADC / SENSORS
J8 is the owned 28 x 17 mm blue ADS1115 module.

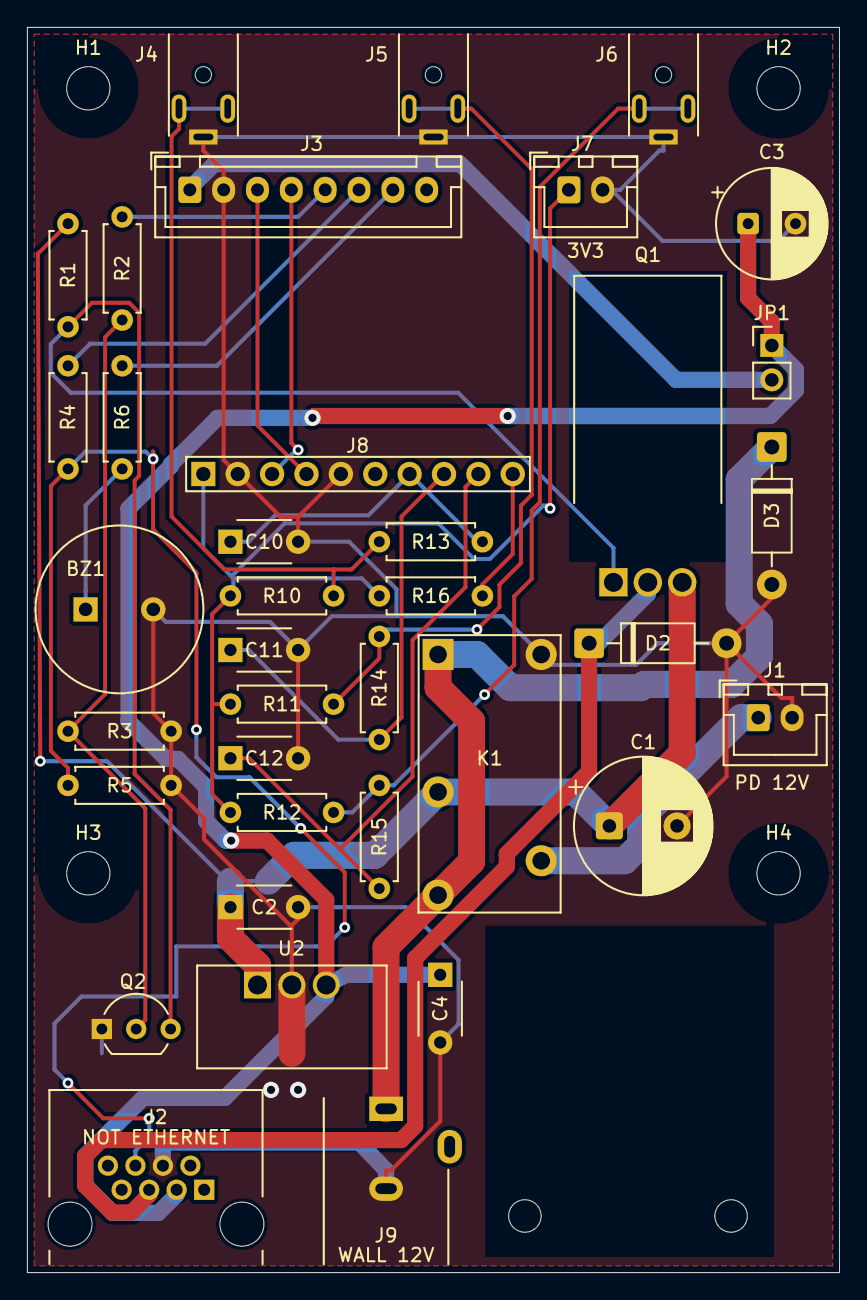
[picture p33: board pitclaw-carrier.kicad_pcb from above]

Board: 2 copper layers, 60.0 x 92.0 mm, 43 parts (0 on the bottom side), 24 nets.

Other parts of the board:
H1, H2, H3, H4: Mount_M3_D3.2_CLEARANCE
H5, H6: ADAFRUIT 5807 M2 / 2.4 NPTH; Adafruit5807_M2_Mount

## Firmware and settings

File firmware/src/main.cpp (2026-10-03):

#ifndef NATIVE_BUILD

#include <Arduino.h>
#include "config.h"
#include "control_outputs.h"

// --- Module headers ---
#include "temp_manager.h"
#include "pid_controller.h"
#include <atomic>
#include "fan_controller.h"
#include "servo_controller.h"
#include "config_manager.h"
#include "cook_session.h"
#include "alarm_manager.h"
#include "error_manager.h"
#include "wifi_manager.h"
#include "web_server.h"
#include "ota_manager.h"
#include "display/ui_init.h"
#include "display/ui_update.h"
#include "display/ui_setup_wizard.h"
#include "display/ui_boot_splash.h"
#include "display/ui_damper_setup.h"

// --- Module instances ---
TempManager     tempManager;
PidController   pidController;
FanController   fanController;
ServoController servoController;
ConfigManager   configManager;
CookSession     cookSession;
AlarmManager    alarmManager;
ErrorManager    errorManager;
WifiManager     wifiManager;
BBQWebServer    webServer;
OtaManager      otaManager;
static DamperSetup g_damperSetup;

static bool ui_cb_touch_calibration(const TouchCalibration& calibration) {
    if (!calibration.valid()) return false;
    auto& saved = configManager.getConfigMutable().touch;
    const auto previous = saved;
    saved = calibration;
    if (configManager.save()) return true;
    saved = previous;
    return false;
}

// --- Control state ---
static float    g_setpoint       = 225.0f;   // Default pit setpoint (degrees F)
static float    g_prevSetpoint   = 225.0f;   // Previous setpoint for change detection
static bool     g_pitReached     = false;     // Has pit ever reached setpoint?
static bool     g_pitControlReady = false;    // Valid PID compute since last probe fault
static uint32_t g_cookStartTime  = 0;         // Epoch when cook timer started
static unsigned long g_graphStartMs = 0;
static uint32_t g_graphRecoveredSec = 0;
static unsigned long g_lastPidMs = 0;         // Last PID computation timestamp

// --- Boot phase state machine ---
enum class BootPhase { SPLASH, WIZARD, RUNNING };
static BootPhase    g_bootPhase    = BootPhase::SPLASH;
static unsigned long g_wizardDoneMs = 0;

// --- CookSession data-source callbacks ---
// These free functions bridge the global module instances into the function-pointer
// interface that CookSession::setDataSources() expects.

static float cb_getPitTemp()   { return tempManager.getPitTemp(); }
static float cb_getMeat1Temp() { return tempManager.getMeat1Temp(); }
static float cb_getMeat2Temp() { return tempManager.getMeat2Temp(); }

static uint8_t cb_getFanPct() {
    return static_cast<uint8_t>(fanController.getCurrentSpeedPct());
}

static uint8_t cb_getDamperPct() {
    return static_cast<uint8_t>(servoController.getCurrentPositionPct());
}

static uint8_t cb_getFlags() {
    uint8_t flags = 0;
    if (pidController.isLidOpen())                    flags |= DP_FLAG_LID_OPEN;
    if (!tempManager.isConnected(PROBE_PIT))          flags |= DP_FLAG_PIT_DISC;
    if (!tempManager.isConnected(PROBE_MEAT1))        flags |= DP_FLAG_MEAT1_DISC;
    if (!tempManager.isConnected(PROBE_MEAT2))        flags |= DP_FLAG_MEAT2_DISC;
    if (errorManager.isFireOut())                     flags |= DP_FLAG_ERROR_FIREOUT;

    AlarmType activeAlarms[MAX_ACTIVE_ALARMS];
    uint8_t count = alarmManager.getActiveAlarms(activeAlarms, MAX_ACTIVE_ALARMS);
    for (uint8_t i = 0; i < count; i++) {
        if (activeAlarms[i] == AlarmType::PIT_HIGH ||
            activeAlarms[i] == AlarmType::PIT_LOW)    flags |= DP_FLAG_ALARM_PIT;
        if (activeAlarms[i] == AlarmType::MEAT1_DONE) flags |= DP_FLAG_ALARM_MEAT1;
        if (activeAlarms[i] == AlarmType::MEAT2_DONE) flags |= DP_FLAG_ALARM_MEAT2;
    }
    return flags;
}

// UI/WebSocket requests are applied on the control task, never the network task.
static std::atomic<int> g_lidEnabledRequest{-1};
static std::atomic<int> g_lidTimeoutRequest{-1};
static std::atomic<int> g_lidActionRequest{0}; //0 none,1 open,2 close/resume; latest action wins.
static void request_lid_enabled(bool enabled) { g_lidEnabledRequest.store(enabled ? 1 : 0); }
static void request_lid_timeout(uint16_t seconds) {
    if (isValidLidTimeoutSeconds(seconds)) g_lidTimeoutRequest.store(seconds);
}
static void request_lid_resume() { g_lidActionRequest.store(2); }
static void request_lid_open() { g_lidActionRequest.store(1); }

// --- WebSocket command callbacks ---
static void ws_onSetpoint(float sp) {
    g_setpoint = sp;
}

static void ws_onAlarm(const char* probe, float target) {
    if (strcmp(probe, "meat1") == 0)      alarmManager.setMeat1Target(target);
    else if (strcmp(probe, "meat2") == 0) alarmManager.setMeat2Target(target);
    else if (strcmp(probe, "pitBand") == 0) alarmManager.setPitBand(target);
}

static void ws_onFanMode(const char* mode) {
    configManager.setFanMode(mode);
    ui_update_settings_state(configManager.isFahrenheit(), configManager.getFanMode());
}

static void ws_onSession(const char* action, const char* format) {
    if (strcmp(action, "new") == 0) {
        cookSession.endSession();
        cookSession.startSession();
        g_cookStartTime = 0;
        g_pitReached = false;
        ui_graph_clear();
        g_graphStartMs = millis();
        g_graphRecoveredSec = 0;
    }
}

// --- Display timing ---
static unsigned long g_lastDisplayMs = 0;
static unsigned long g_lastGraphMs   = 0;

// --- UI callbacks ---
static bool ui_cb_damper_setup(DamperSetupAction action, int value) {
    const uint32_t now = millis();
    if (action == DamperSetupAction::Begin) {
        if (g_damperSetup.state().active) return false;
        fanController.off(); pidController.resetIntegrator();
        g_damperSetup.begin(servoController.getCalibration(), servoController.getCurrentPulseUs(), now);
        return true;
    }
    if (!g_damperSetup.state().active) return false;
    fanController.off();
    switch (action) {
        case DamperSetupAction::Jog:
            if (!g_damperSetup.jog(value, now)) return false;
            servoController.setPulseWidth(g_damperSetup.state().pulseUs); return true;
        case DamperSetupAction::MarkClosed: return g_damperSetup.mark(true, now);
        case DamperSetupAction::MarkOpen: return g_damperSetup.mark(false, now);
        case DamperSetupAction::Test:
            if (!g_damperSetup.test(value, now)) return false;
            servoController.setPulseWidth(g_damperSetup.state().pulseUs); return true;
        case DamperSetupAction::Stop:
            g_damperSetup.stop(); servoController.detach(); return true;
        case DamperSetupAction::Save: {
            if (!g_damperSetup.state().ready()) return false;
            auto& saved = configManager.getConfigMutable().damper;
            const auto previous = saved;
            saved = g_damperSetup.state().endpoints;
            if (!configManager.save()) { saved = previous; return false; }
            servoController.setCalibration(saved);
            break;
        }
        case DamperSetupAction::Cancel: break;
        default: return false;
    }
    g_damperSetup.end();
    pidController.resetLidDetection(); // Fresh control computation before outputs resume.
    g_pitControlReady = false;
    g_lastPidMs = now - PID_SAMPLE_MS;
    g_lastDisplayMs = now - 1000;
    return true;
}
static void ui_cb_setpoint(float sp) {
    g_setpoint = sp;
    ui_update_setpoint(g_setpoint);
}

static void ui_cb_meat_target(uint8_t probe, float target) {
    if (probe == 1) {
        alarmManager.setMeat1Target(target);
        ui_update_meat1_target(alarmManager.getMeat1Target());
    }
    if (probe == 2) {
        alarmManager.setMeat2Target(target);
        ui_update_meat2_target(alarmManager.getMeat2Target());
    }
}

static void ui_cb_alarm_ack() {
    alarmManager.acknowledge();
}

static void ui_cb_units(bool isFahrenheit) {
    configManager.setUnits(isFahrenheit ? "F" : "C");
    ui_set_units(isFahrenheit);
}

static void ui_cb_fan_mode(const char* mode) {
    configManager.setFanMode(mode);
}

static void ui_cb_new_session() {
    cookSession.endSession();
    cookSession.startSession();
    g_cookStartTime = 0;
    g_pitReached = false;
    ui_graph_clear();
    g_graphStartMs = millis();
    g_graphRecoveredSec = 0;
}

static void ui_cb_factory_reset() {
    configManager.factoryReset();
    ESP.restart();
}

// --- Setup wizard hardware test (non-blocking) ---
enum class HwTest { NONE, FAN, SERVO, BUZZER };
static HwTest g_hwTest = HwTest::NONE;
static unsigned long g_hwTestStartMs = 0;

static void wiz_fan_test() {
    fanController.setSpeed(75);
    fanController.update();
    g_hwTest = HwTest::FAN;
    g_hwTestStartMs = millis();
}

static void wiz_servo_test() {
    servoController.setPosition(100);
    g_hwTest = HwTest::SERVO;
    g_hwTestStartMs = millis();
}

static void wiz_buzzer_test() {
    alarmManager.setBuzzer(true);
    g_hwTest = HwTest::BUZZER;
    g_hwTestStartMs = millis();
}

static void wiz_complete() {
    configManager.setSetupComplete(true);
    configManager.save();
    Serial.println("[BOOT] Setup wizard complete");
}

static void ui_cb_wifi_action(const char* action) {
    if (strcmp(action, "disconnect") == 0) {
        wifiManager.disconnect();
    } else if (strcmp(action, "reconnect") == 0) {
        wifiManager.reconnect();
    } else if (strcmp(action, "setup_ap") == 0) {
        wifiManager.startAP();
    }
}

// ---------------------------------------------------------------------------
// setup()
// ---------------------------------------------------------------------------
void setup() {
    // 1. Serial
    Serial.begin(115200);
    delay(500);  // Allow USB-CDC to connect

    Serial.println();
    Serial.println("========================================");
    Serial.printf("  Pit Claw v%s\n", FIRMWARE_VERSION);
    Serial.println("  Board: WT32-SC01 Plus (ESP32-S3)");
    Serial.println("========================================");
    Serial.println();
    Serial.printf("[BOOT] PSRAM: %u bytes, free heap: %u bytes\n",
                  ESP.getPsramSize(), ESP.getFreeHeap());

    // 2. Load configuration from LittleFS
    configManager.begin();
    const AppConfig& cfg = configManager.getConfig();

    // 3. Initialize display and show boot splash immediately
    //    Splash is visible while remaining hardware modules initialize.
    ui_set_touch_calibration(cfg.touch);
    ui_set_touch_calibration_callback(ui_cb_touch_calibration);
    ui_damper_setup_set_callbacks(ui_cb_damper_setup, []() { return g_damperSetup.state(); });
    ui_init();
    ui_boot_splash_init();
    // Paint the splash before blocking setup, without waiting for a refresh tick.
    lv_refr_now(nullptr);

    // 4. Initialize I2C bus and temperature probes (ADS1115)
    tempManager.begin();

    // Apply per-probe calibration coefficients and offsets from saved config
    for (uint8_t i = 0; i < NUM_PROBES; i++) {
        const ProbeSettings& ps = configManager.getProbeSettings(i);
        tempManager.setCoefficients(i, ps.a, ps.b, ps.c);
        tempManager.setOffset(i, ps.offset);
    }
    // Controller, alarms, stored history and web payloads always use Fahrenheit.
    tempManager.setUseFahrenheit(true);
    ui_set_units(configManager.isFahrenheit());

    // 5. Initialize PID controller with saved tunings
    pidController.begin(cfg.pid.kp, cfg.pid.ki, cfg.pid.kd);
    pidController.setLidDetectionEnabled(configManager.isLidDetectionEnabled());
    pidController.setLidTimeoutSeconds(configManager.getLidTimeoutSeconds());

    // 6. Initialize fan PWM output
    fanController.begin();

    // 7. Initialize servo / damper output
    servoController.setCalibration(cfg.damper);
    servoController.begin();

    // 8. Initialize alarm manager (buzzer)
    alarmManager.begin();
    alarmManager.setPitBand(cfg.alarms.pitBand);

    // 9. Initialize error detection
    errorManager.begin();

    // 10. Connect WiFi (splash screen visible during connection)
    wifiManager.onPortalStart([]() { webServer.setEnabled(false); });
    wifiManager.begin();

    // 11. Start HTTP server and WebSocket, pass module references
    webServer.setModules(&tempManager, &pidController, &fanController,
                         &servoController, &configManager, &cookSession,
                         &alarmManager, &errorManager);
    webServer.begin(!wifiManager.isAPMode());
    webServer.onSetpoint(ws_onSetpoint);
    webServer.onAlarm(ws_onAlarm);
    webServer.onSession(ws_onSession);
    webServer.onFanMode(ws_onFanMode);
    webServer.onLidEnabled(request_lid_enabled);
    webServer.onLidTimeout(request_lid_timeout);
    webServer.onResumeLid(request_lid_resume);
    webServer.onOpenLid(request_lid_open);

    // 12. Initialize OTA updates (needs the AsyncWebServer to register /update route)
    otaManager.begin(webServer.getAsyncServer());

    // 13. Recover any existing cook session from flash
    cookSession.begin();
    cookSession.setDataSources(cb_getPitTemp, cb_getMeat1Temp, cb_getMeat2Temp,
                               cb_getFanPct, cb_getDamperPct, cb_getFlags);

    // 14. Wire up dashboard callbacks and set initial state
    ui_set_callbacks(ui_cb_setpoint, ui_cb_meat_target, ui_cb_alarm_ack);
    ui_set_settings_callbacks(ui_cb_units, ui_cb_fan_mode, ui_cb_new_session, ui_cb_factory_reset);
    ui_set_wifi_callback(ui_cb_wifi_action);
    ui_set_lid_callbacks(request_lid_enabled, request_lid_resume, request_lid_open);
    ui_set_lid_timeout_callback(request_lid_timeout);
    ui_update_lid_detection(pidController.isLidDetectionEnabled(), false, 0, false, pidController.getLidTimeoutSeconds());

    // Set initial display state
    ui_update_setpoint(g_setpoint);
    ui_update_meat1_target(alarmManager.getMeat1Target());
    ui_update_meat2_target(alarmManager.getMeat2Target());
    ui_update_settings_state(configManager.isFahrenheit(), configManager.getFanMode());

    // Pre-populate graph from recovered session data
    {
        uint32_t sessionPoints = cookSession.getPointCount();
        const DataPoint* firstPoint = cookSession.getPoint(0);
        uint32_t previousTimestamp = firstPoint ? firstPoint->timestamp : 0;
        for (uint32_t i = 0; i < sessionPoints; i++) {
            const DataPoint* dp = cookSession.getPoint(i);
            if (dp) {
                g_graphRecoveredSec += sessionPointElapsed(previousTimestamp, dp->timestamp);
                previousTimestamp = dp->timestamp;
                ui_graph_add_point(
                    dp->pitTemp / 10.0f,
                    dp->meat1Temp / 10.0f,
                    dp->meat2Temp / 10.0f,
                    g_setpoint,
                    (dp->flags & DP_FLAG_PIT_DISC) != 0,
                    (dp->flags & DP_FLAG_MEAT1_DISC) != 0,
                    (dp->flags & DP_FLAG_MEAT2_DISC) != 0,
                    g_graphRecoveredSec
                );
            }
        }
    }

    g_graphStartMs = millis();

    // 15. Log "Setup complete" with IP address
    Serial.println();
    Serial.printf("[BOOT] Setup complete. IP: %s\n", wifiManager.getIPAddress().c_str());
    Serial.println();

    g_lastPidMs = millis();
    g_lastDisplayMs = millis();
    g_lastGraphMs = millis();
    ui_boot_splash_restart_timer();
}
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

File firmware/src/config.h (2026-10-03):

#pragma once

// --- Pin Assignments (WT32-SC01 Plus Extension Connector) ---
#define PIN_SDA         10
#define PIN_SCL         11
#define PIN_FAN_PWM     12
#define PIN_SERVO       13
#define PIN_BUZZER      14
#define PIN_SPARE       21

// --- ADC Channels (ADS1115) ---
#define ADC_CHANNEL_PIT   0
#define ADC_CHANNEL_MEAT1 1
#define ADC_CHANNEL_MEAT2 2
#define ADC_CHANNEL_SUPPLY 3  // Carrier AIN3 measures probe excitation (+3V3_A)

// --- ADS1115 ---
#define ADS1115_ADDR    0x48
#ifndef NATIVE_BUILD
#define ADS1115_GAIN    GAIN_ONE    // +/- 4.096V range
#endif

// --- Voltage Divider ---
#define REFERENCE_RESISTANCE  10000.0   // 10K ohm reference resistor
#define ADC_MAX_VOLTAGE       4.096     // ADS1115 at GAIN_ONE
#define ADC_MAX_VALUE         32767     // 16-bit signed
#define ADC_SUPPLY_MIN_RAW    24000     // 3.0 V at GAIN_ONE (125 uV/count)
#define ADC_SUPPLY_MAX_RAW    28800     // 3.6 V at GAIN_ONE

// --- Steinhart-Hart Coefficients (Thermoworks Pro-Series) ---
#define THERM_A  7.3431401e-04
#define THERM_B  2.1574370e-04
#define THERM_C  9.5156860e-08

// --- PID Defaults ---
#define PID_KP          4.0
#define PID_KI          0.03    // Build airflow faster during a sustained temperature shortfall
#define PID_KD          5.0
#define PID_TUNING_VERSION 2   // Version 1 used 4.0 / 0.02 / 5.0
#define PID_SAMPLE_MS   4000    // Compute every 4 seconds
#define PID_OUTPUT_MIN  0.0
#define PID_OUTPUT_MAX  100.0
#define PID_SETTLING_ENTER_F 10.0f  // Internal temperatures are always Fahrenheit
#define PID_SETTLING_EXIT_F  15.0f  // Hysteresis preserves warm-up damping after a large drop

// --- Fan Control ---
#define FAN_PWM_FREQ       100     // Provisional two-wire power PWM; bench-verify blower
#define FAN_PWM_CHANNEL    0
#define FAN_PWM_RESOLUTION 10      // 100 Hz needs >=9 bits with the S3 40 MHz LEDC clock
#define SERVO_PWM_CHANNEL  2       // Timer 1; separate from fan, buzzer and backlight
#define SERVO_PWM_TIMER    (SERVO_PWM_CHANNEL / 2)
#define SERVO_PWM_FREQ     50
#define SERVO_PWM_RESOLUTION 14    // 1.22 us per tick at 50 Hz on ESP32-S3
#define BUZZER_PWM_CHANNEL 4       // Timer 2; fan uses timer 0, backlight uses timer 3
#define FAN_KICKSTART_PCT  100     // Full supply voltage for reliable startup
#define FAN_KICKSTART_MS   500     // for 500ms
#define FAN_MIN_SPEED      15      // Minimum sustained speed %
#define FAN_LONGPULSE_THRESHOLD 10 // Below 10%, use long-pulse mode
#define FAN_LONGPULSE_CYCLE_MS 10000 // 10-second cycle

// --- Servo (Damper) ---
#define SERVO_MIN_US    544     // 0 degrees
#define SERVO_MAX_US    2400    // 180 degrees
#define DAMPER_CLOSED   0       // Servo angle for closed
#define DAMPER_OPEN     90      // Servo angle for full open

// --- Split-Range Fan+Damper ---
#define FAN_ON_THRESHOLD   30   // Default fan-on threshold (runtime value from configManager)

// --- Temperature Reading ---
#define TEMP_SAMPLE_INTERVAL_MS  1000   // Read probes every 1 second
#define TEMP_AVG_SAMPLES         4      // Average 4 readings
#define TEMP_EMA_ALPHA           0.2    // EMA smoothing factor (lower = smoother, less derivative noise)

// --- Lid-Open Detection ---
#define LID_OPEN_DROP_PCT   6    // 6% drop below setpoint triggers lid-open
#define LID_OPEN_RECOVER_PCT 2   // Recover/arm near the target (internal Fahrenheit)
#define LID_OPEN_ARM_MS     30000UL  // 30 seconds continuously within +/-2%
#define LID_OPEN_TIMEOUT_MS 120000UL // Default; configurable at runtime
#define LID_TIMEOUT_MIN_SECONDS 30
#define LID_TIMEOUT_MAX_SECONDS 600
#define LID_TIMEOUT_STEP_SECONDS 30
constexpr bool isValidLidTimeoutSeconds(unsigned seconds) {
    return seconds >= LID_TIMEOUT_MIN_SECONDS && seconds <= LID_TIMEOUT_MAX_SECONDS &&
           seconds % LID_TIMEOUT_STEP_SECONDS == 0;
}

// --- Cook Session ---
#define SESSION_BUFFER_SIZE     600     // RAM buffer samples
#define SESSION_SAMPLE_INTERVAL 5000    // 5 seconds between data points
#define SESSION_FLUSH_INTERVAL  60000   // Flush to LittleFS every 60 seconds
#define SESSION_FILE_PATH       "/session.dat"

// --- Config ---
#define FILESYSTEM_MOUNT_PATH "/littlefs"
#define CONFIG_FILE_PATH  "/config.json"

// --- Web Server ---
#define WEB_PORT          80
#define WS_PATH           "/ws"
#define WS_MAX_CLIENTS    4
#define WS_SEND_INTERVAL  1500   // Send data every 1.5 seconds

// Browser checks/downloads from GitHub. Does not disable manual OTA at /update.
#ifndef ENABLE_RELEASE_UPDATES
#define ENABLE_RELEASE_UPDATES 0
#endif

// --- Alarms ---
#define ALARM_PIT_BAND_DEFAULT  15.0    // +/- 15F
#define ALARM_BUZZER_FREQ       4000    // TDK PS1240P02BT rated frequency
#define ALARM_BUZZER_DURATION   500     // 500ms beep
#define ALARM_BUZZER_PAUSE      500     // 500ms pause between beeps
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

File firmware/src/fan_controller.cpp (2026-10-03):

#include "fan_controller.h"

#ifndef NATIVE_BUILD
#include <Arduino.h>
#endif

FanController::FanController()
    : _targetPct(0.0f)
    , _currentPct(0.0f)
    , _currentDuty(0)
    , _kickStartActive(false)
    , _kickStartEndMs(0)
    , _longPulseActive(false)
    , _longPulseCycleStartMs(0)
    , _wasOff(true)
    , _manualMode(false)
    , _pwmReady(false)
{
}

void FanController::begin() {
#ifndef NATIVE_BUILD
    pinMode(PIN_FAN_PWM, OUTPUT);
    digitalWrite(PIN_FAN_PWM, LOW);
    _pwmReady = ledcSetup(FAN_PWM_CHANNEL, FAN_PWM_FREQ, FAN_PWM_RESOLUTION) != 0;
    if (!_pwmReady) {
        Serial.println("[FAN] PWM setup failed; blower output remains off.");
        return;
    }
    ledcAttachPin(PIN_FAN_PWM, FAN_PWM_CHANNEL);
    ledcWrite(FAN_PWM_CHANNEL, 0);

    Serial.printf("[FAN] PWM initialized: pin=%d, freq=%dHz, resolution=%d-bit\n",
                  PIN_FAN_PWM, FAN_PWM_FREQ, FAN_PWM_RESOLUTION);
#endif
    _currentDuty = 0;
    _currentPct = 0.0f;
    _wasOff = true;
}

void FanController::setSpeed(float percent) {
    if (_manualMode) return;

    // Clamp to valid range
    if (percent < 0.0f) percent = 0.0f;
    if (percent > 100.0f) percent = 100.0f;

    _targetPct = percent;
}

void FanController::update() {
    if (_manualMode) return;

#ifndef NATIVE_BUILD
    unsigned long now = millis();
#else
    unsigned long now = 0;
#endif

    // --- Handle kick-start phase ---
    if (_kickStartActive) {
        if (now >= _kickStartEndMs) {
            // Kick-start done, apply the real target speed
            _kickStartActive = false;
            // Fall through to normal speed logic below
        } else {
            // Still in kick-start: keep at kick-start speed
            uint8_t duty = percentToDuty((float)FAN_KICKSTART_PCT);
            _currentPct = (float)FAN_KICKSTART_PCT;
            _currentDuty = duty;
            writePWM(duty);
            return;
        }
    }

    float effectivePct = _targetPct;

    // --- Off ---
    if (effectivePct <= 0.0f) {
        _wasOff = true;
        _longPulseActive = false;
        _currentPct = 0.0f;
        _currentDuty = 0;
        writePWM(0);
        return;
    }

    // --- Kick-start: transitioning from 0% to any speed ---
    if (_wasOff && effectivePct > 0.0f) {
        _wasOff = false;
        _kickStartActive = true;
        _kickStartEndMs = now + FAN_KICKSTART_MS;

        uint8_t duty = percentToDuty((float)FAN_KICKSTART_PCT);
        _currentPct = (float)FAN_KICKSTART_PCT;
        _currentDuty = duty;
        writePWM(duty);
        return;
    }

    _wasOff = false;

    // --- Long-pulse mode: below FAN_LONGPULSE_THRESHOLD ---
    if (effectivePct > 0.0f && effectivePct < (float)FAN_LONGPULSE_THRESHOLD) {
        // Instead of constant low PWM, cycle between min speed and off
        // over a FAN_LONGPULSE_CYCLE_MS period.
        // The on-fraction is proportional to the target percentage / threshold.
        if (!_longPulseActive) {
            _longPulseActive = true;
            _longPulseCycleStartMs = now;
        }

        unsigned long elapsed = now - _longPulseCycleStartMs;
        unsigned long cycleMs = FAN_LONGPULSE_CYCLE_MS;
        unsigned long posInCycle = elapsed % cycleMs;

        // On-time fraction: target / threshold
        float onFraction = effectivePct / (float)FAN_LONGPULSE_THRESHOLD;
        unsigned long onTimeMs = (unsigned long)(onFraction * cycleMs);

        if (posInCycle < onTimeMs) {
            // ON phase: run at min speed
            uint8_t duty = percentToDuty((float)FAN_MIN_SPEED);
            _currentPct = (float)FAN_MIN_SPEED;
            _currentDuty = duty;
            writePWM(duty);
        } else {
            // OFF phase
            _currentPct = 0.0f;
            _currentDuty = 0;
            writePWM(0);
        }
        return;
    }

    // --- Normal speed: apply min-speed clamping ---
    _longPulseActive = false;

    if (effectivePct > 0.0f && effectivePct < (float)FAN_MIN_SPEED) {
        effectivePct = (float)FAN_MIN_SPEED;
    }

    uint8_t duty = percentToDuty(effectivePct);
    _currentPct = effectivePct;
    _currentDuty = duty;
    writePWM(duty);
}

void FanController::off() {
    _targetPct = 0.0f;
    _kickStartActive = false;
    _longPulseActive = false;
    _manualMode = false;
    _wasOff = true;
    _currentPct = 0.0f;
    _currentDuty = 0;
    writePWM(0);
}

float FanController::getCurrentSpeedPct() const {
    return _currentPct;
}

uint8_t FanController::getCurrentDuty() const {
    return _currentDuty;
}

bool FanController::isKickStarting() const {
    return _kickStartActive;
}

void FanController::setManualDuty(uint8_t duty) {
    _manualMode = true;
    _currentDuty = duty;
    _currentPct = (float)duty / 255.0f * 100.0f;
    writePWM(duty);
}

void FanController::writePWM(uint8_t duty) {
#ifndef NATIVE_BUILD
    if (_pwmReady) {
        // Keep the public duty range at 0..255 while using a wider hardware timer.
        const uint32_t maxDuty = (1U << FAN_PWM_RESOLUTION) - 1;
        ledcWrite(FAN_PWM_CHANNEL, (uint32_t(duty) * maxDuty + 127) / 255);
    }
#endif
}

uint8_t FanController::percentToDuty(float pct) {
    if (pct <= 0.0f) return 0;
    if (pct >= 100.0f) return 255;
    return (uint8_t)(pct * 255.0f / 100.0f + 0.5f);
}

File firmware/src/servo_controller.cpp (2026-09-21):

#include "servo_controller.h"

#ifndef NATIVE_BUILD
#include <Arduino.h>
#include <hal/gpio_ll.h>
#endif

ServoController::ServoController()
    : _currentPulseUs(_calibration.closedUs)
    , _attached(false)
    , _pwmReady(false)
{
}

void ServoController::begin() {
    detach();
#ifndef NATIVE_BUILD
    pinMode(PIN_SERVO, OUTPUT);
    digitalWrite(PIN_SERVO, LOW);
    _pwmReady = ledcSetup(SERVO_PWM_CHANNEL, SERVO_PWM_FREQ, SERVO_PWM_RESOLUTION) != 0;
    if (!_pwmReady) Serial.println("[SERVO] PWM setup failed; signal held low.");
#else
    _pwmReady = true;
#endif

    // Start at closed position
    setPosition(0);

#ifndef NATIVE_BUILD
    Serial.printf("[SERVO] GPIO%d channel %d: %lu Hz, closed=%u us, open=%u us\n",
                  PIN_SERVO, SERVO_PWM_CHANNEL, (unsigned long)getPwmFrequencyHz(), _calibration.closedUs, _calibration.openUs);
#endif
}

void ServoController::setPosition(float percent) {
    writeMicroseconds(_calibration.pulseAt(percent));
}

void ServoController::setCalibration(const DamperCalibration& calibration) {
    if (calibration.valid()) _calibration = calibration; // No movement on configuration alone.
}

void ServoController::setPulseWidth(uint16_t us) {
    if (us < SERVO_MIN_US) us = SERVO_MIN_US;
    if (us > SERVO_MAX_US) us = SERVO_MAX_US;
    writeMicroseconds(us);
}

void ServoController::setAngle(uint8_t angleDeg) {
    if (angleDeg > 180) angleDeg = 180;

    uint16_t us = angleToMicroseconds((float)angleDeg);
    writeMicroseconds(us);
}

uint8_t ServoController::getCurrentAngle() const {
    return uint8_t(std::lround((_currentPulseUs - SERVO_MIN_US) * 180.0f / (SERVO_MAX_US - SERVO_MIN_US)));
}

float ServoController::getCurrentPositionPct() const {
    return _calibration.percentAt(_currentPulseUs);
}

void ServoController::detach() {
    if (_attached) {
#ifndef NATIVE_BUILD
        ledcWrite(SERVO_PWM_CHANNEL, 0);
        ledcDetachPin(PIN_SERVO);
        pinMode(PIN_SERVO, OUTPUT);
        digitalWrite(PIN_SERVO, LOW);
        Serial.println("[SERVO] Signal stopped.");
#endif
        _attached = false;
    }
}

void ServoController::writeMicroseconds(uint16_t us) {
    _currentPulseUs = us;
    if (!_pwmReady) return;
#ifndef NATIVE_BUILD
    // Keep a continuous 50 Hz train. Preload the requested pulse before routing
    // the pin, including after Stop, so reattachment cannot emit a neutral pulse.
    const uint32_t ticks = (uint64_t(us) * SERVO_PWM_FREQ * (1UL << SERVO_PWM_RESOLUTION) + 500000) / 1000000;
    ledcWrite(SERVO_PWM_CHANNEL, ticks);
#endif
    if (!_attached) {
#ifndef NATIVE_BUILD
        ledcAttachPin(PIN_SERVO, SERVO_PWM_CHANNEL);
        // Arduino's attach reads the *latched* duty, which may still be zero
        // until the next 20 ms frame. Reapply after binding the pin/timer.
        ledcWrite(SERVO_PWM_CHANNEL, ticks);
#endif
        _attached = true;
    }
}

uint32_t ServoController::getPwmFrequencyHz() const {
#ifndef NATIVE_BUILD
    return ledcReadFreq(SERVO_PWM_CHANNEL);
#else
    return 0;
#endif
}

uint32_t ServoController::getPwmDutyTicks() const {
#ifndef NATIVE_BUILD
    return ledcRead(SERVO_PWM_CHANNEL);
#else
    return 0;
#endif
}

ServoSignalSample ServoController::sampleSignal() const {
    ServoSignalSample sample;
#ifndef NATIVE_BUILD
    // Enable only the pad's input receiver. pinMode(INPUT/OUTPUT) would reset
    // its output matrix routing and disturb the servo being diagnosed.
    gpio_ll_input_enable(&GPIO, static_cast<gpio_num_t>(PIN_SERVO));
    sample.highUs = pulseIn(PIN_SERVO, HIGH, 50000);
    sample.lowUs = pulseIn(PIN_SERVO, LOW, 50000);
#endif
    return sample;
}

uint16_t ServoController::angleToMicroseconds(float angle) const {
    // Linear interpolation from 0-180 degrees to SERVO_MIN_US-SERVO_MAX_US
    // Direct angle tests use the full range; saved endpoints set damper travel.
    if (angle < 0.0f) angle = 0.0f;
    if (angle > 180.0f) angle = 180.0f;

    float us = (float)SERVO_MIN_US +
               (angle / 180.0f) * (float)(SERVO_MAX_US - SERVO_MIN_US);
    return (uint16_t)(us + 0.5f);
}

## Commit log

2026-09-08 Add Rev B carrier and enclosure designs and stabilize firmware
    Capture the carrier KiCad sources, BOM and fabrication packages, enclosure
    models and print exports, and supporting design review artifacts.
    Bring up the WT32-SC01 Plus display, touch, PSRAM and PWM; align probe sampling
    with the carrier and stop control outputs when the pit probe is unavailable.
    Fix Wi-Fi provisioning, wizard QR state, the splash-to-dashboard freeze,
    filesystem serving and ownership of web error messages.
    Validation: 132 native tests pass; firmware and simulator builds pass.
    Headless LVGL regression reproduces the boot failure and passes after the fix.
    USB testing confirms display/touch operation and valid liv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
    [adafruit-5807-husb238.brd, adafruit-5991-husb238.brd, adafruit-ads1115-qt.brd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]
2026-09-08 Improve touch responsiveness and web UI compatibility
    Use immediate LVGL navigation, wall-clock timing, full-width tab targets, and immediate feedback while preserving splash reset timing.
    Support reverse-proxy paths and scoped caches, make GitHub release checks opt-in while retaining manual OTA, and fix the mobile header layout. Include regression checks and deployment documentation.
    [config.h, main.cpp, ui_setup_wizard.cpp]
2026-09-08 Refine landscape touchscreen UI and temperature editing
    Unify rounded cards and controls, align navigation spacing, and improve contrast and touch sizing. Preserve committed editor values and use Fahrenheit internally with consistent Celsius display conve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
    Keep active alerts visible across main screens, label graph history with elapsed time, and improve setup navigation and feedback. Include production LVGL interaction checks and rendered design review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
    Validated firmware and simulator builds, 132 native tests, LVGL interaction checks including 123 navigation taps, and successful board upload with flash verification.
2026-09-09 Polish touchscreen typography and graph navigation
    Keep degree symbols aligned across unit changes, probe disconnections, and compact alarm layouts. Refine status labels and edit icons, and update regression checks and production screen captures.
2026-09-12 Add validated Fusion enclosure and accessory mounting inserts
    Include the populated carrier, corrected connector orientation, four-anchor
    display retainer, and reinforced removable probe fascia. Add four interior M3
    mounting inserts with external screw access on a 72 x 74 mm pattern.
    Include editable Fusion models, STL/STEP releases, fit coupons, mounting DXF,
    assembly guides, and geometry verification records. R11 passes 26 geometry
    checks and 10 mesh checks; protected PCB and fabrication files are unchanged.
    [carrier-bottom.step, carrier-bottom.stl, carrier-case.scad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]
2026-09-14 Keep only the latest controller enclosure release
    Remove obsolete controller models, previews, releases and upgrade scripts.
    Retain r11 and the separate blower/damper assembly, update documentation and
    point mechanical-interface exports directly at the current reference.
    Remove prior-release dependencies from verification and packaging. Refresh
    the self-contained package after all 26 geometry and 10 mesh checks pass;
    the Fusion model, print meshes, STEP files and protected hardware are unchanged.
    [bbq-case.scad, carrier-bottom-draft.stl, carrier-bottom.step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]
2026-09-14 Fix fascia guidance through the full rail depth
    Replace the short raised front cover and open inner groove with constant
    captured rail profiles along the complete 9 mm engagement. Preserve probe,
    PCB and mounting-insert datums, and show outer/middle/inner CAD sections.
    Regenerate the latest Fusion/STL package and joint coupons. Add independent
    capture checks at five depths per guide; 31 geometry checks, 10 mesh checks
    and native component/guide verification pass. Reuse the existing top/retainer.
    [carrier-bottom.step, carrier-bottom.stl, carrier-case.scad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]
2026-09-14 Add clamped coupons for enclosure clearance tuning
    Provide a tighter guide and smaller fascia gaps while retaining the probe
    and rail datums. Include the actual closure post and screw grip, plus current
    clearance controls, to separate shell closure from fascia binding.
    The candidate passes 32 geometry checks and five mesh checks. Preserve the
    released R12 model and production files pending a physical fit comparison.
    [bottom.stl, candidate.scad, carrier-interface.scad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]
2026-09-15 Increase guide running clearance above and below the rail
    Raise the fit-test roof gap to 0.40 mm normal and add 0.30 mm underside
    relief. Keep two ramped seating lands at the original datum so the fascia
    is located before its probe holes reach the jack collars.
    Retain the 0.20 mm side gap and all other test/release parts. Regenerate
    only the bottom coupon; 37 geometry checks and five mesh checks pass.
    [bottom.stl, candidate.scad, guide-capture-early-check-intersection.stl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]
2026-09-15 Increase fit-test guide side clearance to 0.30 mm
    Add 0.10 mm at the receiver outer wall following the improved physical fit
    after light filing. Preserve upper/lower clearance, support lands, the rail,
    and all reusable test parts. Regenerate only the bottom coupon.
    All 37 geometry and five mesh checks pass; full R12 release remains unchanged.
    [bottom.stl, candidate.scad, guide-capture-early-check-intersection.stl]
2026-09-15 Increase fit-test heat-set pilots to 4.2 mm
    Size candidate insert pilots for the measured 4–5 mm insert outside diameter,
    keeping 5 mm pilot depth, screw passages and guide geometry unchanged.
    Regenerate bottom/top coupons and verify pilot diameters in STL sections.
    All 37 geometry checks and five mesh checks pass. The fascia, controls and
    released full enclosure remain unchanged pending the physical insert fit.
    [bottom.stl, candidate.scad, nominal-shell-closure-check-intersection.stl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]
2026-09-15 Complete r13 enclosure with accepted guide and insert fits
    [candidate.scad, carrier-bottom.step, carrier-bottom.stl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]
2026-09-15 Remove obsolete r6 and r7 enclosure working files
    [carrier-case.scad, carrier-interface.scad]
2026-09-18 Add printed Adafruit 5807 base with rear stops and solder relief
    [adafruit5807-base.scad, adafruit5807-base.step, adafruit5807-base.stl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]
2026-09-21 Fix lid pause startup and add persistent UI controls
    [config.h, config_manager.cpp, main.cpp]
2026-09-21 Treat meat probes as optional and add manual lid toggle
2026-09-21 Add reversible preview and saving of touch calibration
2026-09-21 Add damper endpoint calibration and manual setup controls
2026-09-21 Drive servo on dedicated precise PWM channel and fix signal stop
    [config.h, servo_controller.cpp, web_server.cpp]
2026-09-21 Restore servo pulse after attach and add GPIO pulse sampling
2026-09-22 Keep damper position tests available before calibration
2026-10-03 Add optional web authentication and stabilize Settings controls
    Protect the web UI, API, WebSockets and OTA with an optional shared password,
    while keeping touchscreen access unchanged. Preserve existing credentials
    through hash-cost migration and save authentication settings atomically.
    Keep temperature editor intent separate from controller telemetry, preserve
    untouched meat targets in partial commands, and load the current interface
    through versioned assets and a network-first offline shell. Avoid WebSocket
    lock inversion and acknowledge firmware uploads before scheduling reboot.
    Validation: firmware and simulator builds from the exact staged snapshot;
    146 native tests; controller/proto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
    [config.h, config_manager.cpp, main.cpp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]
2026-10-03 Improve PID settling and migrate default integral gain
    Increase the factory integral gain from 0.02 to 0.03 so sustained temperature
    shortfalls build airflow demand faster. Use clamped anti-windup within 10F
    of target, returning to conditional warm-up damping beyond 15F without
    resetting accumulated PID history.
    Migrate only the exact legacy factory tuning, preserving custom gains,
    explicit rollback settings, and damper calibration. Cover tuning response,
    settling hysteresis, overshoot correction and resets with real QuickPID tests.
    Validation: firmware and simulator builds from the PID-only staged snapshot;
    146 native tests; tuning, settling, protocol/migration and authentication checks.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
    [config.h, config_manager.cpp]
2026-10-03 Fix firmware recovery and alerts; simplify unused state
    Suppress pit-low alarms during lid pauses, preserve the lid warning across navigation, reject implausible temperatures, and recover session records and graph elapsed time correctly.
    Remove redundant session bookkeeping, unused fan and OTA fields, and duplicated WebSocket broadcasting. Add alarm, graph, temperature and storage regression coverage.
    Validation: 157 native tests, controller/configuration integration, authentication integration, web UI regressions, LVGL interaction checks, and firmware/simulator builds passed.
    [alarm_manager.cpp, cook_session.cpp, fan_controller.cpp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]
